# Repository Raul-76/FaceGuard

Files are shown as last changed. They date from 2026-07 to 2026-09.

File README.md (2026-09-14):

# 🔐 FaceGuard - Smart Lock with Facial Recognition (ESP32-S3)







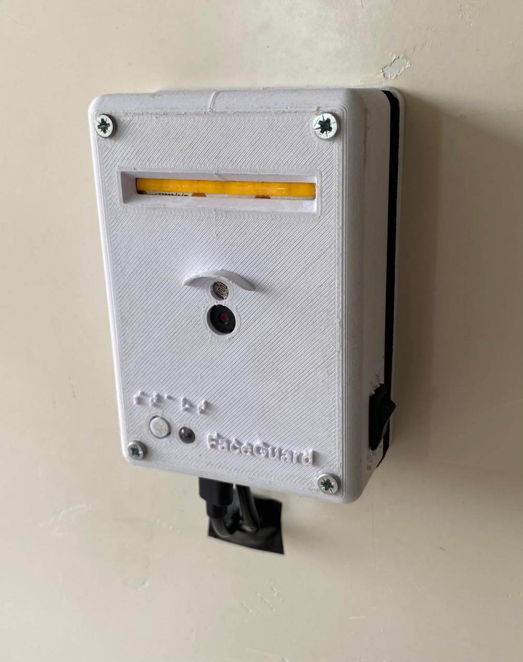
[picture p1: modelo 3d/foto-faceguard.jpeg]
FaceGuard schematic


This project implements a **facial recognition security lock** built around an **ESP32-S3 board (Freenove ESP32-S3-WROOM CAM, OV2640 sensor)**. The system comprises three components: embedded firmware (handling computer vision and lock control), a web dashboard for monitoring and control, and a custom 3D-printed enclosure.

**Video presentation:** A full walkthrough of the project (team introduction, live demo, and the challenges we faced) is available [on YouTube](https://youtu.be/lPA_LZTQk2s).

---

## 🧩 System Overview

The ESP32-S3 acts as a local network HTTP server, continuously capturing video, performing facial detection and recognition, and driving hardware peripherals—including the **servo motor that physically engages and disengages the lock**. The dashboard, accessed via a local web browser, connects to the ESP32 over HTTP to display the live video stream and enable remote system control.

Recognition decisions are not based on a single frame; instead, each access attempt collects a **burst of valid frames and requires a minimum number of positive votes** to unlock the mechanism, thereby reducing false positives. Before inference takes place, a **quality gate** discards blurred frames or those with excessive motion, and camera exposure is fixed to ensure stable embeddings.

### 🔧 Hardware Used

<!-- Schematic --> 
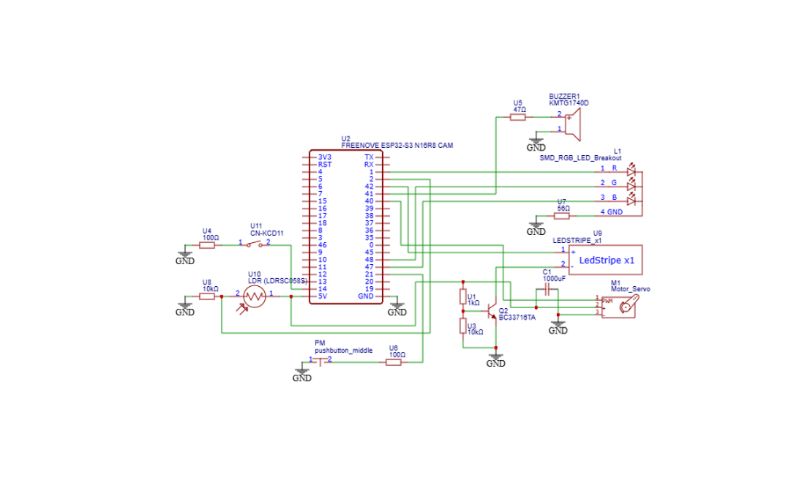
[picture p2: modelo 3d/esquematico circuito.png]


- **ESP32-S3 (Freenove ESP32-S3-WROOM CAM, OV2640)** — image capture and facial recognition processing.
- **Servo Motor** — physically locks/unlocks the mechanism at the end of each access attempt.
- **Green LED** — indicates **Access Granted**.
- **Red LED** — indicates **Access Denied**.
- **Blue LED ("breathing" RGB effect)** — indicates the system is processing a recognition attempt.
- **COB Led strip** — dynamic lighting, for low brightness environment.
- **LDR (Photoresistor)** — sensor used to determine the dutycycle fed to the led strip.
- **Buzzer** — plays distinct melodies for access granted, access denied, alarm/tamper alerts, and system startup. 
- **Physical button** — manually triggers a recognition attempt.
- **Deep Sleep switch** — puts the system into ultra-low power mode; the board wakes up automatically when the switch is toggled.
- **3D-printed case** — custom enclosure designed to house the camera and other electronic components.

---
## The Firmware

The firmware is written in C++ on the Arduino framework and uses EloquentEsp32cam for face detection, recognition and enrollment, ESP32Servo (adapted for the ESP32-S3) for the latch, and esp_http_server for the web interface. It runs face recognition entirely on the board, with no server or cloud service involved.

### Architecture

- **Dual-Core Task Separation:** FreeRTOS splits the workload across both cores. Core 0 serves HTTP requests and the video stream, while core 1 runs the recognition pipeline, so that network traffic never stalls inference.
- **Shared Frame Buffer:** Camera capture happens exclusively in the main loop, writing to a PSRAM buffer. The HTTP server only reads from it, guarded by a FreeRTOS mutex, which avoids frame buffer contention between recognition and streaming.
- **Memory Configuration:** A Huge APP partition scheme and OPI PSRAM are required to fit the recognition model alongside the camera pipeline on the target board.
- **Network Interfaces:** An MJPEG stream on port 81 and a REST endpoint on port 80, which serve the dashboard described above.

### Recognition Pipeline

<!-- Recognition decision flow -->
<p align="center">
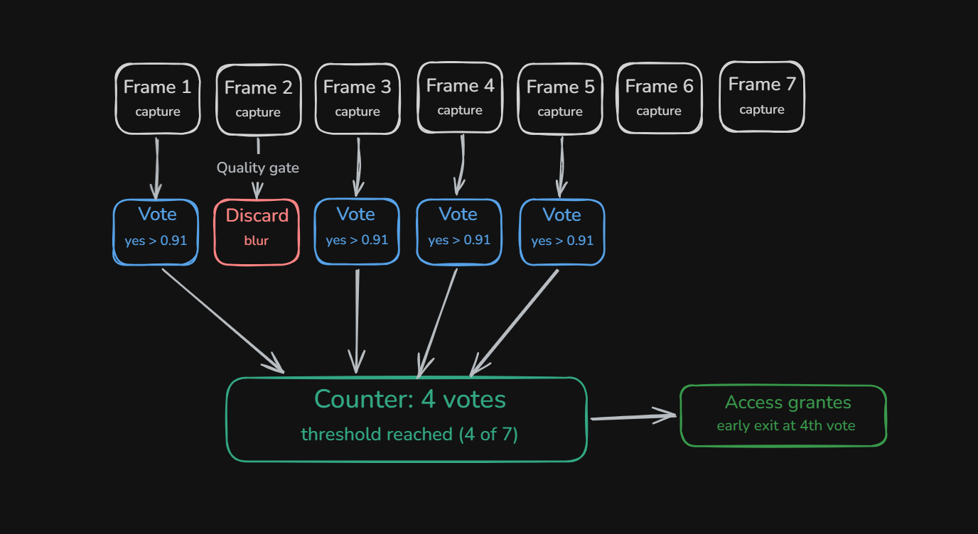
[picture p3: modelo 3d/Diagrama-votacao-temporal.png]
  
</p>

<p align="center">
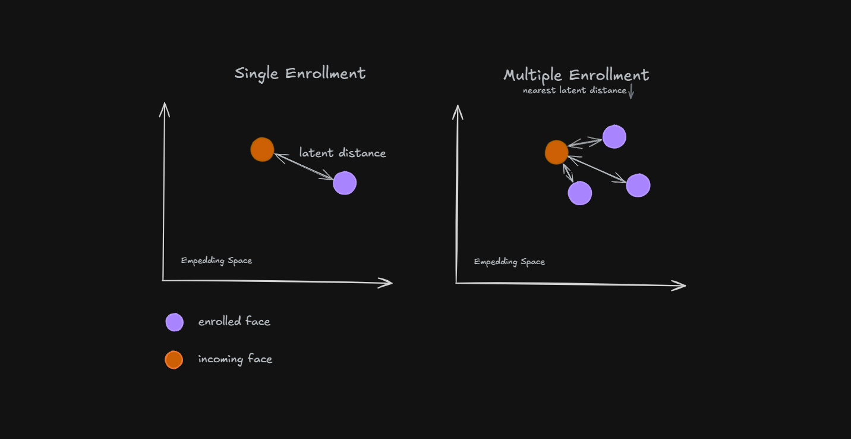
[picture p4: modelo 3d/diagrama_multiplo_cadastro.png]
  
</p>

- **K-of-N Voting:** A decision layer sits around the model. Instead of unlocking on a single frame, the firmware requires agreement across consecutive frames, which reduces both false accepts and false rejects caused by momentary bad frames.
- **Multi-Sample Enrollment:** A user can be enrolled from several captures, covering a wider region of the embedding space and improving recognition across angles and lighting.
- **Quality Gating:** Captures that do not meet the quality criteria are rejected at enrollment, so that poor samples never enter the database.
- **Illumination Control:** The LDR feedback loop adjusts illumination, keeping the face adequately lit before inference runs.

---

## The Web Dashboard

The Dashboard (located in the `dashboard` folder) is a modern interface built using HTML, CSS (dark mode with glassmorphism), and JavaScript (Vanilla). It connects directly to the ESP32 camera via HTTP requests to view the live video stream and control the system. And it is accessible from both desktop and mobile browsers.
<!-- 📸 Print do Dashboard -->

<p align="center">
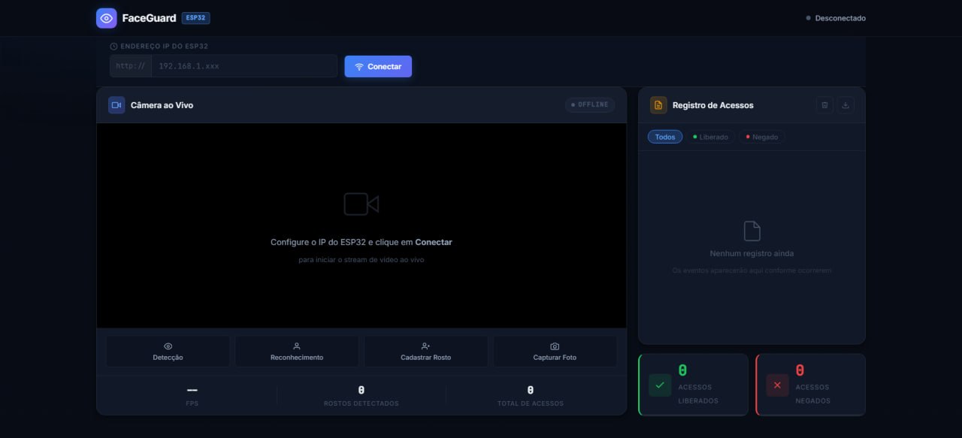
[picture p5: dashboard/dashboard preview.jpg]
FaceGuard Dashboard
  
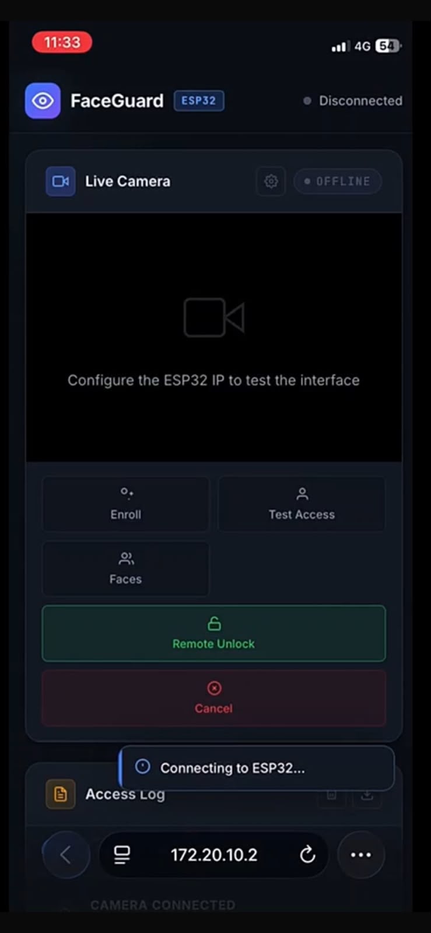
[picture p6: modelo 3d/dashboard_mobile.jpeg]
FaceGuard Dashboard on mobile
  
</p>

### Key Features

- **Live Video Stream:** Real-time viewing of the MJPEG stream provided by the ESP32, with automatic reconnection in the event of a connection loss.
- **Access Security:** Login-protected startup screen for administrators.
- **Camera Controls:**
- **Access Test:** Triggers a live recognition attempt on the camera. 
- **Face Enrollment:** Single or multiple registration (capturing several samples) of the same face, with an option to cancel an ongoing enrollment. 
- **Face Management:** Screen to view registered faces and rename or delete users (individually or in batches). 
- **Remote Unlock:** Remotely releases the lock via the dashboard, without requiring facial recognition.
- **Access Logs:** History of access attempts (granted and denied), with event filters (All, Granted, Denied) and CSV export functionality.
- **Real-Time Statistics:** Counters for granted and denied access attempts displayed visually on the interface.

---

## 3D Model

The enclosure was custom-designed to house the ESP32-S3, the servo-operated lock, and other electronic components, and was subsequently 3D printed. <!-- 📸 3D model screenshot/photo -->
<p align="center">
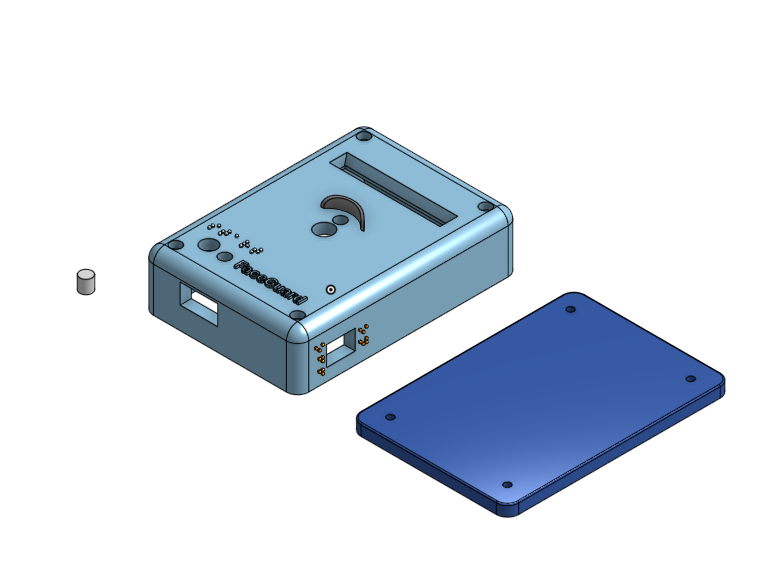
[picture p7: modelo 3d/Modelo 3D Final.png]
3D model of the FaceGuard case - View 1

</p>

<!-- 📸 3D model screenshot/photo -->
<p align="center">
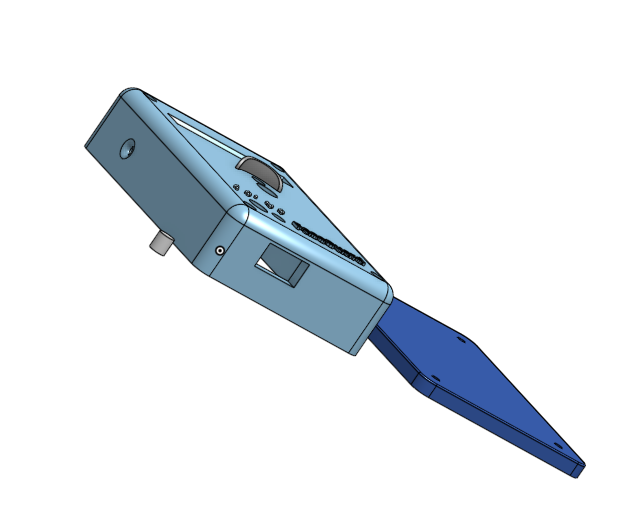
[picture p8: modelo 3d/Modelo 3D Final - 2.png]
3D model of the FaceGuard case - View 2

</p>

<p align="center">
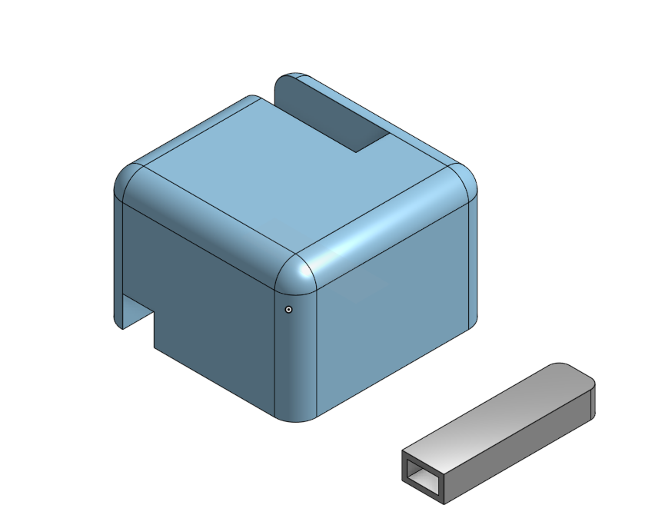
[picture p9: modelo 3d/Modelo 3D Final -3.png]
3D model of the Servo Motor case

</p>

---

## ⚙️ How It Works

The ESP32 acts as an HTTP server on the local network, while the Dashboard functions as the client (frontend).

1. The **Dashboard** requires the ESP32's local network IP address to establish a connection (the device is also advertised via **mDNS** as `FaceGuard.local`).
2. The system splits communication across **two ports** on the same IP to prevent command processing from stalling during video transmission:
- **Port 81:** Dedicated exclusively to the video stream. 
- `http://{IP}:81/stream` — live video stream (MJPEG). 
- **Port 80 (Default):** Dedicated to the interface, API, and commands. 
- `http://{IP}/` — debug/monitoring page hosted on the board itself. 
- `http://{IP}/info` — real-time system status (JSON): recognition state, LDR reading, recent access logs, etc.
- `http://{IP}/control?cmd={command}` — executes commands such as starting registration, testing access, remote unlocking, or renaming/deleting a face. 
- `http://{IP}/faces` — returns the list of all faces stored in the ESP32's memory. 3. **Access attempt workflow:** the physical button (or remote command) triggers the capture of a burst of frames → each frame passes through a quality gate (sharpness and motion) → valid frames are compared against registered faces → upon reaching the minimum number of positive matches, the green LED lights up, the success melody plays, and the servo unlocks the lock for a few seconds before locking it again; otherwise, the red LED lights up and the access-denied melody plays.
4. The fill light (COB) is automatically adjusted via a closed-loop LDR circuit, maintaining stable facial illumination even in dark environments.
5. When the deep sleep switch is closed, the system enters an ultra-low power state and the lock remains engaged; it wakes up automatically when the switch is opened.
6. ESP32 IP settings and access logs are saved locally in the browser (`LocalStorage`), preserving the history even after the page is reloaded.

---

## 📚 Libraries and Development Environment

The firmware was developed using the Arduino IDE (ESP32 Core 2.0.14), with the environment configured for the **ESP32-S3** board (OPI PSRAM enabled, "Huge APP" partition scheme). Key libraries used:

- `eloquent_esp32cam.h` — camera capture and high-level pipeline for ESP32-CAM/S3.
- `eloquent_esp32cam/face/detection.h` — face detection.
- `eloquent_esp32cam/face/recognition.h` — face recognition (registration, comparison, and similarity voting).
- `WiFi.h` — local network connection.
- `esp_http_server.h` — native ESP-IDF HTTP server (lighter than `WebServer.h`), used for API routes and the MJPEG stream.
- `ESP32Servo.h` — control of the lock's servo motor.
- `ESPmDNS.h` — device discovery on the local network via `FaceGuard.local`.
- `driver/rtc_io.h` / `esp_sleep.h` — configuration of the wake-up pin and deep sleep mode.

> The code was based on the **Freenove ESP32-S3-WROOM CAM** board with the **OV2640** sensor. ---

## 📁 Repository Structure

```
FaceGuard/
├── reconhecimento_facial/   # ESP32-S3 Firmware (Back-End) — camera, detection, recognition, and lock control
│   ├── reconhecimento_facial.ino
│   ├── dashboard.h          # HTML/CSS/JS for the debug page embedded on the board
│   └── partitions.csv       # Partition scheme (Huge APP)
├── dashboard/                # Web Interface (Front-End) — stream, control, and logs
│   ├── index.html
│   ├── app.js
│   ├── style.css
│   └── dashboard preview.jpg
├── modelo 3d/                 # 3D modeling files for the case (.stl, screenshots, and sketches)
│   ├── Face Guard.stl
│   ├── esboço 3d.stl
│   ├── esboço 3d.html
│   └── *.png
└── README.md
```

---

## 🚀 How to Use

1. Upload the code found in `reconhecimento_facial/reconhecimento_facial.ino` to the ESP32-S3-WROOM CAM board using the Arduino IDE (Core 2.0.14, OPI PSRAM, Huge APP partition).
2. Note the IP address displayed in the Serial Monitor when the ESP32 connects to Wi-Fi (or use `FaceGuard.local` via mDNS).
3. Open the `dashboard/index.html` file in any modern web browser.
4. In the top bar, enter your ESP32's IP address (or `FaceGuard.local`) and click **Connect**.
5. Register authorized faces using the Dashboard's face management tab.
6. Enjoy the system's features by controlling the camera and lock directly from the Dashboard!

---

## 👥 Team and Credits

| Member | Responsibility | GitHub | Contact |
|---|---|---|---|
| **Raul Jesus dos Santos** | Front-End Development — building the FaceGuard Dashboard | [@Raul-76](https://github.com/Raul-76) | [Email](raul.js.fla@gmail.com) |
| **Carlos Eduardo Guimarães** | 3D modeling of the camera/system enclosure | [@VoIkmer](https://github.com/VoIkmer) | [Email](cguimaraes03@gmail.com) |
| **Caio Marcelo Mazza** | Back-End — ESP32-S3 firmware (camera, facial recognition, and lock control) | [@Caiompmazza](https://github.com/caiompmazza) | [Email](caio.mpmazza@gmail.com) |

---

Completed local access control project using embedded hardware and a web interface, combining facial recognition, a motorized lock, and a real-time monitoring interface.

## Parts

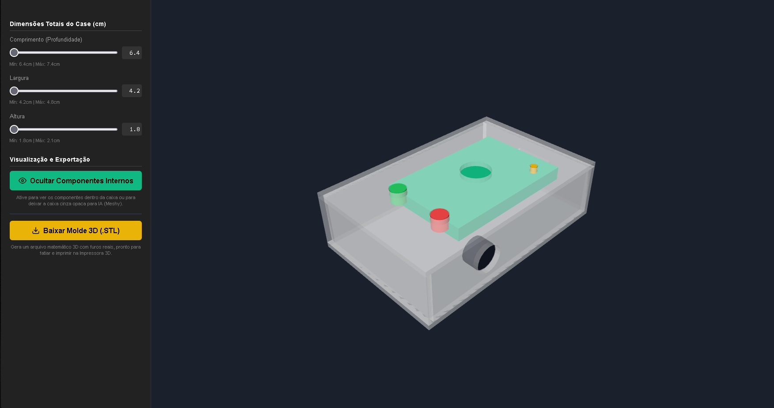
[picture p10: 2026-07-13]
modelo 3d/esboço 3d c componentes.png

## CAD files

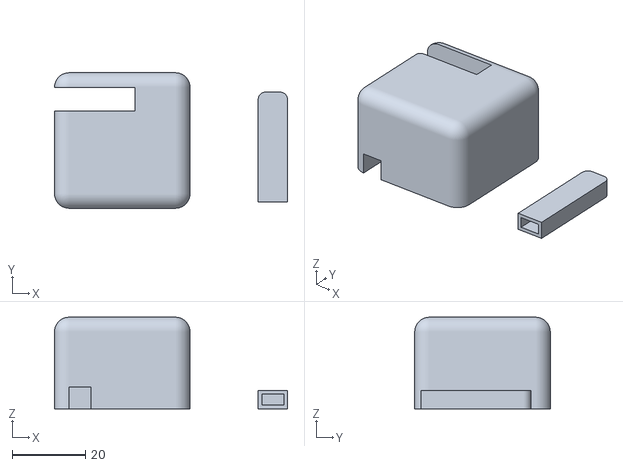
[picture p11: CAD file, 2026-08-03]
modelo 3d/Servo Motor Case.stl
63.6 x 37.0 x 25.0

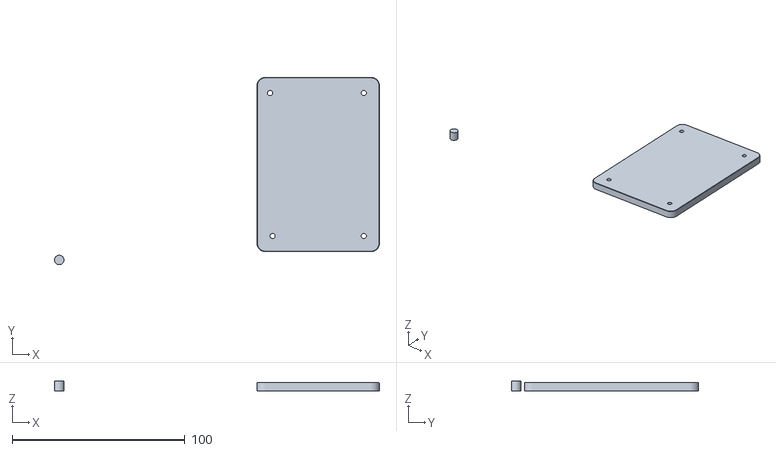
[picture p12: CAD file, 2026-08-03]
modelo 3d/FaceGuard Back-Push Button.stl
188.2 x 108.5 x 6.00

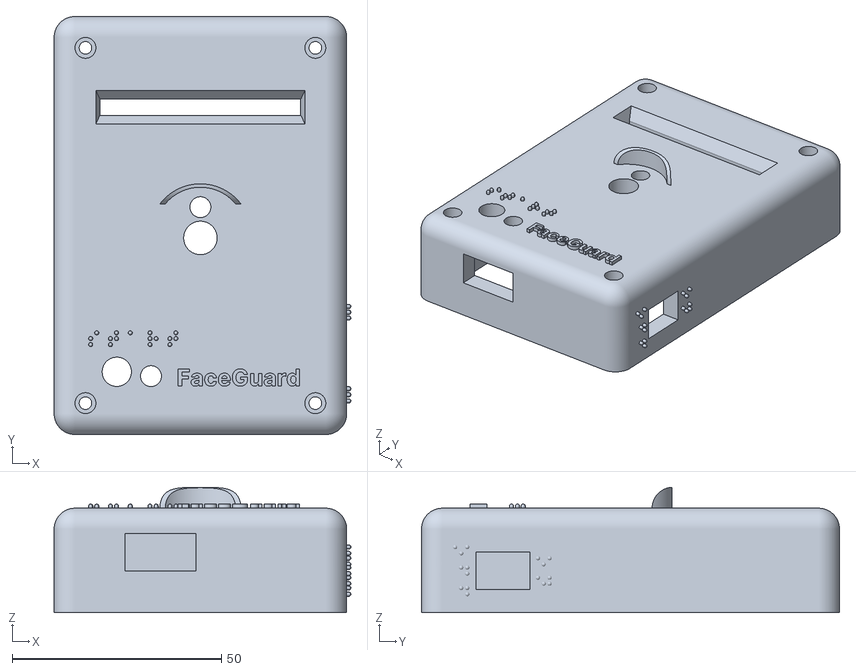
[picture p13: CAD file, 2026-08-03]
modelo 3d/FaceGuard Case.stl
71.0 x 100.0 x 30.0

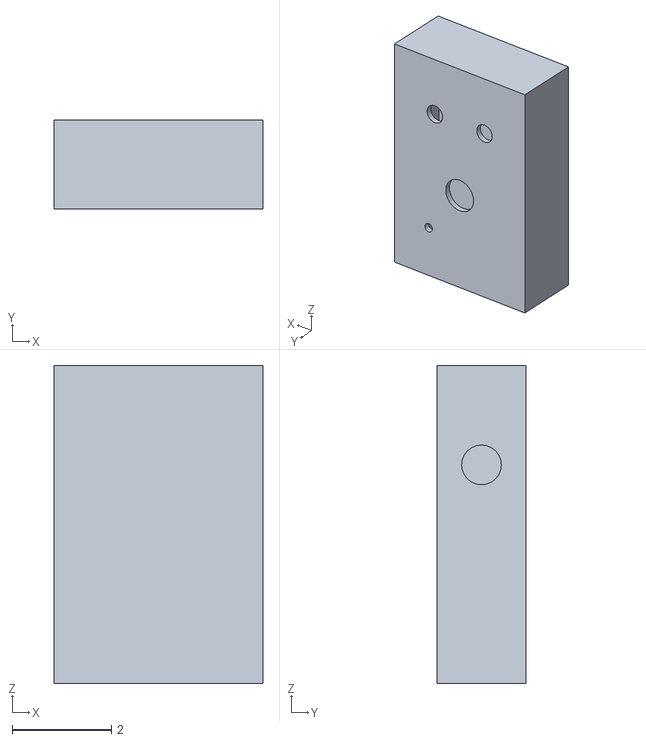
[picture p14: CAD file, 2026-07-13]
modelo 3d/esboço 3d.stl
4.20 x 1.80 x 6.40

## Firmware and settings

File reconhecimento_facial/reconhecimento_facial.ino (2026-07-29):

/**
 * ESP32-S3 Face Recognition — Fechadura com reconhecimento facial (v3)
 * Freenove ESP32-S3-WROOM CAM | OV2640
 * Core 2.0.14 | OPI PSRAM | Huge APP | Serial 115200 + New Line
 *
 * ARQUITETURA GERAL
 *   - loop() captura frames continuamente e publica no servidor MJPEG
 *     (assim o feed no navegador mostra EXATAMENTE o frame usado na
 *     inferencia -- serve pra focar a lente e calibrar limiares).
 *   - O reconhecimento NAO decide por 1 frame. Uma "tentativa" coleta
 *     ate JANELA_N frames validos e exige VOTOS_K votos a favor.
 *     Isso derruba o falso-positivo esporadico, que e o modo de falha
 *     tipico quando similaridade de impostor chega perto da do dono.
 *   - Antes de gastar inferencia, um quality-gate descarta frame ruim.
 */

#include <eloquent_esp32cam.h>
#include <eloquent_esp32cam/face/detection.h>
#include <eloquent_esp32cam/face/recognition.h>

#include <WiFi.h>
#include <esp_http_server.h> // servidor HTTP nativo do IDF (mais leve que WebServer.h)
#include <math.h>            // sin() do pulso do LED

#include <ESP32Servo.h>

#include <ESPmDNS.h>

#include "dashboard.h"
#include "driver/rtc_io.h" // pull-up no dominio RTC (sobrevive ao sono)
#include "esp_sleep.h"     // deep sleep

using eloq::camera;
using eloq::face::detection;
using eloq::face::recognition;

// ==================== PINOS ====================
// LED azul saiu do GPIO14 (que virou o switch de sono) e foi pro 47.
// (K) LED VERDE saiu do GPIO2 e foi pro 48, liberando o 2 para o LDR.
const int pinoVermelho = 1;
const int pinoVerde = 48; // (K) ERA 2 -- movido para liberar o ADC1
const int pinoAzul = 47;
const int pinoBuzzer = 41;
const int pinoLuz = 42; // gate do MOSFET que aciona o COB

// (J) FOTORRESISTOR: GPIO 2 = ADC1_CH1.
// TEM que ser ADC1 (GPIO 1..10 no S3): o ADC2 nao funciona com WiFi ligado.
const int pinoLDR = 2;

// ==================== CONTROLE DE ILUMINACAO (J) ====================
// A realimentacao agora usa o LDR. Divisor de tensao sugerido:
//     3.3V --- [LDR] ---+--- GPIO2 (ADC1_CH1)
//                       |
//                    [10k]
//                       |
//                      GND
// Mais luz -> menor resistencia do LDR -> LEITURA MAIOR no ADC.
//
// CALIBRACAO OBRIGATORIA: rode o comando 'l' e anote a leitura crua no seu
// ambiente. Os valores abaixo sao ponto de partida, nao verdade absoluta --
// dependem do LDR, do resistor e da luz do local.
const int LDR_ALVO = 3000;   // leitura desejada (0..4095)
const int BANDA_MORTA = 150; // nao mexe se estiver perto do alvo.
                             // Sem banda morta o controle OSCILA em torno
                             // do setpoint, e luz piscando estraga a
                             // consistencia dos embeddings.
const int DUTY_MIN = 70;      // nunca apaga de vez durante a operacao
const int DUTY_MAX = 255;
const int PASSO_DUTY = 2; // ajuste INCREMENTAL, nao proporcional:
                          // mover pouco por vez tambem evita oscilacao
int dutyLuz = 70;         // ponto de partida

// Botao momentaneo que dispara uma tentativa de reconhecimento.
const int iniciarReconhecimento = 21;

// Switch de trava do deep sleep. TEM que ser RTC GPIO (0..21 no S3):
// so o dominio RTC fica vivo dormindo, entao so esses pinos acordam.
const gpio_num_t pinoDeepSleep = GPIO_NUM_14;

// ==================== SERVO DA FECHADURA ====================
Servo fechaduraServo;
const int pinoServo = 40;          // GPIO40 livre no projeto
const int SERVO_FECHADO = 0;       // trancado
const int SERVO_ABERTO  = 90;      // destrancado
const uint32_t TEMPO_ABERTO_MS = 7000; // tempo que fica aberta antes de fechar

// ==================== BUZZER ====================
// Cada som e um vetor de pares {frequencia_Hz, duracao_ms}, terminado
// por {0,0}. Frequencia 0 com duracao > 0 = pausa (silencio).
struct Nota {
  int frequencia;
  int duracao;
};

// Logica sonora do sistema: SOBE = positivo, DESCE = negativo.
// E o mesmo vocabulario de leitoras HID/Intelbras.

// Acesso permitido: arpejo ascendente ("liberado").
const Nota somPortaAberta[] = {
    {523, 50}, {659, 50}, {784, 50}, {1047, 200}, {0, 0}};

// Alarme/tamper: alternancia aguda e estridente (padrao de alerta).
const Nota somAlarme[] = {
    {2500, 300}, {2000, 300}, {2500, 300}, {2000, 300}, {0, 0}};

// Boot: bipe curto + bipe mais alto = "sistema pronto".
const Nota somBoot[] = {{1800, 80}, {0, 40}, {2300, 200}, {0, 0}};

// Acesso negado: descendente e grave. Seco, e inconfundivel com o de
// abertura justamente porque desce e termina no registro grave.
const Nota somAcessoNegado[] = {{600, 150}, // ataque imediato
                                {450, 150}, // transicao rapida
                                {300, 300}, // finalizacao grave e seca
                                {0, 0}};

// ==================== VOTACAO POR RAJADA ====================

#define PISO_SIM                                                               \
  0.91f                  // similaridade minima pra um frame virar VOTO.
                         // Este e o gate REAL de seguranca -- deve ficar
                         // acima do teto observado do impostor e abaixo
                         // do chao observado do dono. MEDIR e ajustar.
#define JANELA_N 7       // teto de frames validos por tentativa
#define VOTOS_K 4        // votos a favor necessarios (K de N)
#define TIMEOUT_MS 12000 // aborta se nao juntar N validos a tempo

// ==================== QUALITY-GATE ====================
// (I) Os limiares de BRILHO foram removidos -- ver nota no cabecalho.
// Sobraram os dois que se apoiam em relacao fisica real com o tamanho do JPEG.
#define MIN_SHARP                                                              \
  3000                  // abaixo disso = desfocado. Com quality fixa,
                        // imagem borrada comprime mais -> JPEG menor.
#define MAX_SHARP 38000 // teto: frame gigante = ruido/anomalia
#define MOV_MAX_DELTA                                                          \
  9000 // salto de tamanho do JPEG entre 2 frames.
       // Cena mudando rapido -> risco de motion blur.

// ==================== EXPOSICAO ====================
// Com exposicao fixa o brilho para de variar entre frames, o que estabiliza
// os embeddings e mata flicker. EXIGE luz constante (COB); e justamente por
// isso o controle do COB via LDR faz sentido: ele mantem a cena estavel.
#define EXPOSICAO_FIXA true
#define AEC_VALOR_FIXO 300 // 0..1200
#define AGC_GANHO_FIXO 0   // 0..30 (ganho baixo = menos ruido)

// ==================== CONFIG ====================
 #define WIFI_SSID "Caio.2g"
//#define WIFI_SSID "WIFI"
 #define WIFI_PASS "28460363"
//#define WIFI_PASS "net12345"

#define JPG_CAP 40000 // teto do buffer compartilhado do stream
#define FRAME_W 240   // camera.resolution.face()
#define FRAME_H 240

// Resultado de uma tentativa.
// FICA AQUI EM CIMA de proposito: o Arduino IDE injeta prototipos
// automaticos no topo do arquivo. Se o enum estiver la embaixo, o prototipo
// de runTentativa() referencia Veredito antes da declaracao
// -> erro "'Veredito' does not name a type".
enum Veredito { PENDENTE, APROVADO, NEGADO, EXPIROU };

// modo do LED azul, escrito pela task da camera, lido pela task do LED
enum EstadoLED { LED_OFF, LED_RESPIRANDO };
volatile EstadoLED estadoLED = LED_OFF;

// pedido de tentativa: setado pelo botao (loop), consumido pela task da camera
volatile bool pedidoReconhecimento = false;

volatile bool pedidoAcessoRemoto = false;

TaskHandle_t handleCamera = nullptr;
TaskHandle_t handleLED = nullptr;


// Prototipos explicitos (nao dependemos da geracao automatica do IDE).
String prompt(String message);
String promptTimeout(String message, uint32_t ms);
void entrarEmDeepSleep();
void doEnroll(String defaultName = "");
void runRecognition();
void enrollMultiplo(int alvo, String defaultName = "");
void publishFrame(const uint8_t *buf, size_t len);
bool frameOk(const char *&motivoOut);
void pulsaLEDEspera();
void sinalizaResultado(int pino, const Nota melodia[]);
Veredito runTentativa();
void tocarMelodia(const Nota melodia[]);
uint16_t lerLDR();
void ajustaLuz();
void testeLuz();
void liberarAcessoRemoto();

bool modoContinuo = false; // 'r' liga: imprime similaridade a cada frame
uint32_t sharpMax = 0;     // pico de nitidez ja visto (guia pra focar a lente)
uint32_t lastPrint = 0;    // throttle do serial no modo continuo
uint32_t ultimoSharp = 0;  // tamanho do frame anterior (detector de movimento)
volatile char httpCommand = 0; // comando web atômico ('c', 'r', 'p', 't', 'm')
char httpCommandName[64] = ""; // nome passado via web
char httpNewCommandName[64] = ""; // novo nome para edicao
String lastAccType = "-";      // "granted", "denied" ou "-"
String lastAccName = "-";      // nome ou "desconhecido"
String enrollStatus = "idle";
String enrollMsg = "-";
volatile bool cancelarCadastro = false;


void tarefaLED(void *pv) {
  for (;;) {
    if (estadoLED == LED_RESPIRANDO) {
      float onda = (sin(millis() / 300.0) + 1) / 2;
      analogWrite(pinoAzul, (int)(onda * 255));
    } else {
      analogWrite(pinoAzul, 0);
    }
    vTaskDelay(pdMS_TO_TICKS(20)); // ~50 updates/s, independe da inferencia
  }
}

void tarefaCamera(void *pv) {
  for (;;) {
    // comando pendente (web ou serial funilam no mesmo httpCommand)
    if (httpCommand != 0) {
      char cmd = httpCommand;
      httpCommand = 0;
      switch (cmd) {
        case 'c': modoContinuo = false; cancelarCadastro = false;
                  updateEnrollStatus("capturing", "starting...");   // sai de "success" na hora
                  doEnroll(httpCommandName[0] ? String(httpCommandName) : ""); break;
        case 'm': modoContinuo = false; cancelarCadastro = false;
                  updateEnrollStatus("capturing", "starting...");   // idem
                  enrollMultiplo(3, httpCommandName[0] ? String(httpCommandName) : ""); break;
        case 'x': cancelarCadastro = true; break;
        case 'o': pedidoAcessoRemoto = true; break;
        case 'k': {
            File src = SPIFFS.open("/fr.bin", "rb");
            File dst = SPIFFS.open("/fr.tmp", "wb");
            bool found = false;
            while(src && dst && src.available()) {
                enrolled_face_t proto;
                src.read((uint8_t*)&proto, sizeof(proto));
                if (String(proto.name) == String(httpCommandName)) {
                    found = true;
                } else {
                    dst.write((uint8_t*)&proto, sizeof(proto));
                }
            }
            if(src) src.close();
            if(dst) dst.close();
            if (found) {
                SPIFFS.remove("/fr.bin");
                SPIFFS.rename("/fr.tmp", "/fr.bin");
                recognition.begin();
            } else {
                SPIFFS.remove("/fr.tmp");
            }
            break;
        }
        case 'e': {
            File src = SPIFFS.open("/fr.bin", "rb");
            File dst = SPIFFS.open("/fr.tmp", "wb");
            bool found = false;
            while(src && dst && src.available()) {
                enrolled_face_t proto;
                src.read((uint8_t*)&proto, sizeof(proto));
                if (String(proto.name) == String(httpCommandName)) {
                    found = true;
                    String newName = String(httpNewCommandName);
                    for (uint8_t i = 0; i < newName.length() && i < 16; i++)
                        proto.name[i] = newName[i];
                    proto.name[newName.length() < 16 ? newName.length() : 16] = '\0';
                }
                dst.write((uint8_t*)&proto, sizeof(proto));
            }
            if(src) src.close();
            if(dst) dst.close();
            if (found) {
                SPIFFS.remove("/fr.bin");
                SPIFFS.rename("/fr.tmp", "/fr.bin");
                recognition.begin();
            } else {
                SPIFFS.remove("/fr.tmp");
            }
            break;
        }
        case 'r': modoContinuo = true;  Serial.println(">> MODO CONTINUO"); break;
        case 'p': modoContinuo = false; Serial.println(">> PAUSADO"); break;
        case 't': pedidoReconhecimento = true; break;
        case 'd': recognition.dump(); break;
        case 'z': sharpMax = 0; Serial.println(">> pico zerado"); break;
        case 'l': modoContinuo = false; testeLuz(); break;
      }
    }

    if (pedidoReconhecimento) {
      pedidoReconhecimento = false;
      runTentativa();
    }

      if (pedidoAcessoRemoto) {
      pedidoAcessoRemoto = false;
      liberarAcessoRemoto();
    }

    // captura + publica sempre (feed vivo)
    if (!camera.capture().isOk()) { vTaskDelay(pdMS_TO_TICKS(30)); continue; }
    publishFrame(camera.frame->buf, camera.frame->len);

    uint32_t sharp = camera.frame->len;
    if (sharp > sharpMax) sharpMax = sharp;

    if (modoContinuo) runRecognition();
    else updateGInfo(0, sharp, sharpMax, lerLDR(), "(pausado)", "-");

    vTaskDelay(pdMS_TO_TICKS(10));
  }
}


/**
 * Toca a melodia de forma BLOQUEANTE (usa delay).
 * Aceitavel aqui porque os sons so tocam em transicoes de estado, nunca
 * durante a captura. O +10ms separa as notas e deixa o bipe "seco".
 */
void tocarMelodia(const Nota melodia[]) {
  int i = 0;
  while (melodia[i].frequencia != 0 || melodia[i].duracao != 0) {
    if (melodia[i].frequencia == 0) {
      noTone(pinoBuzzer);
      delay(melodia[i].duracao); // pausa
    } else {
      tone(pinoBuzzer, melodia[i].frequencia, melodia[i].duracao);
      delay(melodia[i].duracao + 10);
    }
    i++;
  }
  noTone(pinoBuzzer);
}
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
void loop() {

  static uint32_t lastWifiCheck = 0;
  if (millis() - lastWifiCheck > 5000) {
    lastWifiCheck = millis();
    if (WiFi.status() != WL_CONNECTED) {
      Serial.println(">> WiFi caiu, reconectando...");
      WiFi.disconnect();
      WiFi.begin(WIFI_SSID, WIFI_PASS);
    }
  }
  // switch -> deep sleep (com debounce)
  if (digitalRead(pinoDeepSleep) == LOW) {
    delay(50);
    if (digitalRead(pinoDeepSleep) == LOW) entrarEmDeepSleep();
  }

  // serial -> vira comando no mesmo canal do web
  if (Serial.available()) {
    String cmd = Serial.readStringUntil('\n');
    cmd.trim();
    if (cmd.startsWith("s")) entrarEmDeepSleep();          // sono e imediato
    else if (cmd.length() > 0) { httpCommand = cmd[0]; httpCommandName[0] = '\0'; }
  }

  // botao -> pedido (borda de descida)
  static bool botaoUltimoEstado = HIGH;
  bool botaoAtual = digitalRead(iniciarReconhecimento);
  if (botaoUltimoEstado == HIGH && botaoAtual == LOW) pedidoReconhecimento = true;
  botaoUltimoEstado = botaoAtual;

  delay(10);
}

/**
 * Modo continuo ('r'): roda inferencia no MESMO frame que foi pro navegador
 * e publica o resultado em /info. Serve pra MEDIR similaridades reais --
 * do dono e de impostores -- e dai calibrar o PISO_SIM da votacao.
 * Nao aciona nada: e diagnostico, nao decisao.
 */
void runRecognition() {
  uint32_t sharp = camera.frame->len;
  uint16_t ldr = lerLDR();

  // Sem rosto na cena.
  if (!recognition.detect().isOk()) {
    updateGInfo(0, sharp, sharpMax, ldr, "-", "-");
    return;
  }

  // Rosto detectado, mas sem match (face:1, name:"?").
  if (!recognition.recognize().isOk()) {
    updateGInfo(1, sharp, sharpMax, ldr, "?", "-");
    return;
  }

  const char *name = recognition.match.name.c_str();
  float sim = recognition.match.similarity;
  char simStr[16];
  snprintf(simStr, sizeof(simStr), "%.4f", sim);

  updateGInfo(1, sharp, sharpMax, ldr, name, simStr);

  // Throttle: imprimir a cada frame inundaria o serial e atrasaria o stream.
  if (millis() - lastPrint > 400) {
    lastPrint = millis();
    Serial.printf("MATCH: %-10s sim=%.4f  sharp=%u  ldr=%u  (%dms)\n", name,
                  sim, (unsigned)sharp, (unsigned)ldr,
                  recognition.benchmark.millis());
  }
}

/**
 * Cadastro simples ('c'): 3s pra voce se posicionar, depois UMA captura.
 * Um unico embedding -- suficiente pra testar, fraco pra uso real.
 * A luz acende aqui tambem: cadastrar sob luz ambiente e depois comparar sob
 * luz do COB derruba a similaridade -- exatamente o problema que o sistema
 * tenta evitar.
 */
void doEnroll(String defaultName) {
  String name = defaultName;
  if (name == "") {
    name = prompt("Nome:");
  }

  analogWrite(pinoLuz, dutyLuz); // acende no duty aprendido

  Serial.println("Position your face. Registering in 3 seconds...");
  for (int i = 0; i < 30;
       i++) { // 30 x 100ms: tempo de sobra pro controle convergir
    if (camera.capture().isOk()) {
      publishFrame(camera.frame->buf, camera.frame->len);
      ajustaLuz();
    }
    delay(100);
  }

  if (!camera.capture().isOk()) {
    Serial.println("ERRO: captura falhou");
    analogWrite(pinoLuz, 0);
    return;
  }
  publishFrame(camera.frame->buf, camera.frame->len);

  // Gate no cadastro e o ponto mais critico do sistema: um embedding
  // gerado de rosto borrado contamina TODAS as comparacoes futuras.
  const char *motivo = "";
  if (!frameOk(motivo)) {
    Serial.printf("ERROR: Poor-quality frame for enrollment (%s). Please try again.\n",
                  motivo);
    analogWrite(pinoLuz, 0);
    return;
  }

  if (!recognition.detect().isOk()) {
    Serial.println("ERRO: nenhum rosto detectado");
    analogWrite(pinoLuz, 0);
    return;
  }

  if (recognition.enroll(name).isOk()) {
    Serial.print("OK, cadastrado: ");
    Serial.println(name);
  } else {
    Serial.println(recognition.exception.toString());
  }

  analogWrite(pinoLuz, 0);
}

/**
 * Multi-enroll ('m'): grava varios embeddings do MESMO nome.
 * Cobre variacoes de angulo e luz, o que sobe a similaridade do dono e abre
 * distancia em relacao ao impostor -- exatamente o que da margem pra ajustar
 * o PISO_SIM.
 * So conta captura que passa no quality-gate; MAX_TENTATIVAS evita laco
 * infinito se a condicao estiver ruim demais.
 */
void enrollMultiplo(int alvo, String defaultName) {
  String nome = defaultName;
  if (nome == "") {
    nome = prompt("Nome para cadastro multiplo:");
  }

  Serial.printf(">> Multi-enrollment for '%s' (target: %d)\n", nome.c_str(), alvo);
  int ok = 0;
  int tentativas = 0;
  const int MAX_TENTATIVAS = alvo * 3;
  const char *motivo = "";
  char buf[96];   // buffer fixo reutilizado -> nao fragmenta o heap

  estadoLED = LED_RESPIRANDO;
  analogWrite(pinoLuz, dutyLuz);

  while (ok < alvo) {
    Serial.printf("   [HEAP livre: %u | maior bloco: %u]\n",
                  (unsigned)ESP.getFreeHeap(),
                  (unsigned)heap_caps_get_largest_free_block(MALLOC_CAP_DEFAULT));
    //vTaskDelay(10 / portTICK_PERIOD_MS);
    
    yield();
    
    if (httpCommand == 'x') {
        cancelarCadastro = true;
        httpCommand = 0; // Limpa a variável para não processar o 'x' duas vezes
    }

    //server.handleClient();

    if (cancelarCadastro) {
      updateEnrollStatus("cancelled", "Enrollment cancelled.");
      Serial.println(">> cancelled");
      estadoLED = LED_OFF; analogWrite(pinoAzul, 0); analogWrite(pinoLuz, 0);
      return;
    }
    if (tentativas >= MAX_TENTATIVAS) {
      snprintf(buf, sizeof(buf), "Failed: only %d/%d after %d attempts", ok, alvo, tentativas);
      updateEnrollStatus("failed", buf);
      Serial.printf(">> %s\n", buf);
      estadoLED = LED_OFF; analogWrite(pinoAzul, 0); analogWrite(pinoLuz, 0);
      return;
    }
    tentativas++;

    snprintf(buf, sizeof(buf), "Capture %d/%d (attempt %d) - hold STILL...", ok + 1, alvo, tentativas);
    updateEnrollStatus("capturing", buf);
    Serial.printf("   %s\n", buf);

    for (int k = 0; k < 12; k++) {
      if (camera.capture().isOk()) publishFrame(camera.frame->buf, camera.frame->len);
      ajustaLuz();
      delay(100);
    }

    if (!camera.capture().isOk()) {
      updateEnrollStatus("capturing", "Capture failed, retrying");
      continue;
    }
    publishFrame(camera.frame->buf, camera.frame->len);

    if (!frameOk(motivo)) {
      snprintf(buf, sizeof(buf), "Discarded (%s), retrying", motivo);
      updateEnrollStatus("capturing", buf);
      continue;
    }

    if (!recognition.detect().isOk()) {
      updateEnrollStatus("capturing", "No face detected, retrying");
      continue;
    }

    if (recognition.enroll(nome).isOk()) {
      ok++;
      snprintf(buf, sizeof(buf), "OK (%d/%d)", ok, alvo);
      updateEnrollStatus("capturing", buf);
      Serial.printf("   %s\n", buf);
    } else {
      updateEnrollStatus("capturing", "enroll error, retrying");
      Serial.println(recognition.exception.toString());
    }
  }

  snprintf(buf, sizeof(buf), "Enrollment done: %d/%d for '%s'", ok, alvo, nome.c_str());
  updateEnrollStatus("success", buf);
  Serial.printf(">> %s\n", buf);
  estadoLED = LED_OFF; analogWrite(pinoAzul, 0); analogWrite(pinoLuz, 0);
}

/**
 * Prompt BLOQUEANTE: insiste ate receber resposta nao-vazia.
 * O bloqueio aqui e desejado -- so e chamado nos cadastros, onde voce
 * acabou de digitar o comando e portanto esta no monitor serial.
 */
String prompt(String message) {
  String answer;
  do {
    Serial.print(message);
    Serial.print(" ");
    while (!Serial.available())
      delay(1);
    answer = Serial.readStringUntil('\n');
    answer.trim();
  } while (answer.length() == 0); // enter vazio -> repete a pergunta
  Serial.println(answer);
  return answer;
}

/**
 * Prompt com TIMEOUT: retorna string vazia se ninguem responder.
 * Usado no boot. Resposta vazia e um resultado valido aqui (significa
 * "nao faca nada"), por isso nao ha o laco de insistencia do prompt().
 */
String promptTimeout(String message, uint32_t ms) {
  Serial.print(message);
  Serial.print(" ");

  uint32_t t0 = millis();
  while (!Serial.available()) {
    if (millis() - t0 > ms) {
      Serial.println("  (sem resposta, seguindo)");
      return "";
    }
    delay(10);
  }

  String answer = Serial.readStringUntil('\n');
  answer.trim();
  Serial.println(answer);
  return answer;
}

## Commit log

2026-07-13 Update badges in README.md
    Removed old badges and added new ones for ESP32-CAM, C++, dashboard, status, and license.
2026-07-20 dashboard dentro do esp32
2026-07-21 Add files via upload
    versões atual (v7) e anteriores do codigo embarcado do esp
    [partitions.csv]
2026-07-22 Dashboard
    Atualização no cadastro de pessoa, mudança na resolução da tela e configuração para usar os comandos do código do reconhecimento facial.
2026-07-23 mudança de arquivos
    [partitions.csv]
2026-07-23 mudança pasta
    [partitions.csv]
2026-07-23 mudança de pasta
    [partitions.csv]
2026-07-24 Parar de rastrear a pasta dashboard e o arquivo .gitignore
2026-07-24 Log do cadastro do rosto no dashboard, notificação final de falha ou sucesso do cadastro
2026-07-26 Update dashboard.h (conexão melhorada e mudanças visuais)
    - apaguei o cache do navegador
    - os dados do webserver agr sao enviados em chunks ele tava enviando tudo de vez
    - removi um chamado pra fotnes do google q tavam pesando
    - e botei pra ele pegar o ip automaticamente no codigo do dashboard, pq parece q ele tava pegando um ip antigo e quando conecta e desconecta do roteador ele muda o ip
    - coloquei o sharp e brilho mas com possibilidade de serem vistos ao apertar um botão
2026-07-27 Update reconhecimento_facial.ino (Multi-threading)
    multiprocessamento para evitar travamentos
    melhoria de conexão com dashboard
    correção de prints em portugues
    aumento de velocidade para cadastros
    mudanca de piso para reconhecimento
2026-07-27 Update reconhecimento_facial.ino (fixei o link de acesso do dashboard)
    [reconhecimento_facial.ino]
2026-07-28 Implementação das seguintes alterações: botão de cancelar, bloquer múltiplos, proibir cadastro múltiplos, lista editavél de cadastro e page de login
2026-07-28 Update dashboard.h
    conexão mais robusta, mas ainda cai com cadastro
    mudei o icone da pagina
    e adicionei novamente o toggle para brilho e sharpness
2026-07-28 Update reconhecimento_facial.ino (servo)
    Servo motor
2026-07-29 Update dashboard.h (resolvi problema de cancelar enroll)
2026-07-29 Update reconhecimento_facial.ino (fix da queda do dashboard e cancelamente de cadastro)
    depois de muito tempo debugando descobri q a queda n era por conexao wifi mais sim por consumo excessivo de ram, apos:
    melhor alocação de recurso de ram
    diminuicao do numero de enrolls
    agora o sistema cadastrar sem cair
    [reconhecimento_facial.ino]
2026-07-29 Update dashboard.h (lista de rostos exibe 1 ao inves de 3)
2026-07-29 Update reconhecimento_facial.ino (lista de rostos agora exibe um por cadastro)
2026-08-04 Update README.md led strip e ldr
2026-09-13 Replace FaceGuard image with updated version
    Updated image reference in README.md for FaceGuard schematic.

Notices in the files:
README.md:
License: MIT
